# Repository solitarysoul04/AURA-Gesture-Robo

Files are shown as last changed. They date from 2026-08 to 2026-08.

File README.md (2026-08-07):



# AURA (Autonomous & Unmanned Reconnaissance Agent) Rover🚙

AURA Rover is a visionary project which I brainstormed during building for Macondo by HackClub. It is an autonomous project that will use a computer vision interface which will incorporate MediaPipe and OpenCV which will detect and read the hand gestures on-board for hopefully successful movement of the rover. This idea was brainstormed to replace the use of joystick and sit back lazy controlling the rover with just your physical hands assisted by ESP32-CAM feed on your system.

## 🌟 Key Features
- Dual-Hand Control: Pinching fingers of left hand will trigger the throttle and right hand gestures will act as an steering using OpenCV and MediaPipe.
- Dual-Band Architecture: Video will be transmitted via ESP32-CAM high-bandwidth FPV Wi-Fi and for Zero-Latency Motor Controls, 2.4GHz RF on nRF24L01 will be used.
- Two HC-SR04 ultrasonic sensors: Since the rover will be autonomous, for safety and instant braking of the rover, two ultrasonic sensors (one at front and another at back) will keep a watch on obstacles and will avoid any crash by stopping rover if something is detected within 15cm and will not accept the wireless commands.

## 🛒 BoM 
| Category | Product Name | SKU | Qty | Price/Unit (INR) | Link |
| :--- | :--- | :--- | :--- | :--- | :--- |
| Electronics | RF Nano Integrated NRF24L01 Wireless Module | 1121399 | 2 | 1159 | [Buy](https://robu.in/?s=1121399&post_type=product) |
| Electronics | Nano CH340 Chip Board Without USB Cable | 16906 | 2 | 195 | [Buy](https://robu.in/?s=16906&post_type=product) |
| Electronics | ESP32-CAM WiFi + Bluetooth Module | R262524 | 1 | 709 | [Buy](https://robu.in/?s=R262524&post_type=product) |
| Electronics | L298N Dual H Bridge Motor Driver | 51971 | 1 | 176 | [Buy](https://robu.in/?s=51971&post_type=product) |
| Electronics | HC-SR04 Ultrasonic Range Finder Sensor | 2444 | 1 | 65 | [Buy](https://robu.in/?s=2444&post_type=product) |
| Power | Pro-Range INR 18650 11.1V 2000mAh 3S1P Li-Ion Battery | 1237659 | 1 | 899 | [Buy](https://robu.in/?s=1237659&post_type=product) |
| Power | LM2596S DC-DC Buck Converter Power Supply | 11548 | 1 | 42 | [Buy](https://robu.in/?s=11548&post_type=product) |
| Power | Battery Charger 3S Li-ion 12.6V 5A | 1158326 | 1 | 1773 | [Buy](https://robu.in/?s=1158326&post_type=product) |
| Hardware | EasyMech Warrior Chassis for Robotics | 43327 | 1 | 1386 | [Buy](https://robu.in/?s=43327&post_type=product) |
| Hardware | Pro-Range 12V 300 RPM Johnson Geared DC Motor | 5728 | 4 | 540 | [Buy](https://robu.in/?s=5728&post_type=product) |
| Hardware | 85mm Large Robot Smart Car Wheel 38mm Wide | 31509 | 4 | 209 | [Buy](https://robu.in/?s=31509&post_type=product) |
| Hardware | 6mm Hex Motor Coupling 30mm Length | 42874 | 4 | 81 | [Buy](https://robu.in/?s=42874&post_type=product) |
| Cabling | Male to Male Jumper Wires 40Pcs 20cm | 7447 | 1 | 46 | [Buy](https://robu.in/?s=7447&post_type=product) |
| Cabling | 10 Wire Male to Female Jumper Wires 20cm | R160077 | 4 | 14 | [Buy](https://robu.in/?s=R160077&post_type=product) |
| Cabling | 22AWG High Quality Ultra Flexible Silicone Wire - Black | 1824995 | 1 | 18 | [Buy](https://robu.in/?s=1824995&post_type=product) |
| Cabling | 22AWG Single Core Teflon Wire - Red | R257340 | 1 | 24 | [Buy](https://robu.in/?s=R257340&post_type=product) |
| Cabling | Female to Female DuPont Line 40 Pin 30cm | 31321 | 1 | 61 | [Buy](https://robu.in/?s=31321&post_type=product) |
| Cabling | Arduino Nano USB A-Mini B 1.2m Cable | 17844 | 1 | 44 | [Buy](https://robu.in/?s=17844&post_type=product) |
| Cabling | USB TO UART TTL 5V 3.3V FT232RL Adapter | 9707 | 1 | 89 | [Buy](https://robu.in/?s=9707&post_type=product) |
| Consumables | Nylon Cable Zip Ties 150mm White (Pack of 100) | 18279 | 1 | 78 | [Buy](https://robu.in/?s=18279&post_type=product) |
| Consumables | Nylon Cable Zip Ties 300mm White (Pack of 100) | 18280 | 1 | 109 | [Buy](https://robu.in/?s=18280&post_type=product) |
| Consumables | Heat Shrink sleeve 20mm Black | R150615 | 1 | 74 | [Buy](https://robu.in/?s=R150615&post_type=product) |
| Consumables | All Purpose Hot Melt Glue Sticks - 5pcs | 6005 | 1 | 79 | [Buy](https://robu.in/?s=6005&post_type=product) |
| Consumables | Noel Solder Wire 60/40 1.00mm 50gm | 720480 | 1 | 299 | [Buy](https://robu.in/?s=720480&post_type=product) |
| Consumables | Noel FLUX soldering paste-10g | 762465 | 1 | 25 | [Buy](https://robu.in/?s=762465&post_type=product) |
| Prototyping | GL-12 840 Points Solderless Breadboard | 24441 | 1 | 59 | [Buy](https://robu.in/?s=24441&post_type=product) |
| Tools | Screwdriver Set 52 in 1 | 972456 | 1 | 800 | [Buy](https://robu.in/?s=972456&post_type=product) |
| Tools | Soldron 50W 230V Soldering Iron | 143296 | 1 | 699 | [Buy](https://robu.in/?s=143296&post_type=product) |
| Tools | TE-801 LED Magnifier PCB Soldering Stand | 17940 | 1 | 441 | [Buy](https://robu.in/?s=17940&post_type=product) |
| Tools | Multitec 02DX Self Adjusting Wire Cutter - Stripper | 617869 | 1 | 256 | [Buy](https://robu.in/?s=617869&post_type=product) |
| Tools | HTC DM-830L Digital Pocket Multimeter | 775689 | 1 | 649 | [Buy](https://robu.in/?s=775689&post_type=product) |
| Tools | Standard Temp 60Watt Hot Melt Glue Gun | 5998 | 1 | 251 | [Buy](https://robu.in/?s=5998&post_type=product) |
| Tools | Stanley Black+DECKER KR5010V Hammer Drill | R111278 | 1 | 2369 | [Buy](https://robu.in/?s=R111278&post_type=product) |

## 📐 3D CAD Model
This build was done natively in Onshape, with the structural layout and stacking of components. 
**[Link to Onshape Public 3D Model](https://cad.onshape.com/documents/1ed37dd0b596b430698f5eb2/w/aa1a3a995dd5a0a3a9e055b1/e/f5aa9d2bf4de66af82fadf2e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)**

## 🛠️ Assembly Instructions

Once I have the required hardware parts I will put the parts together and wire the hardware/electronics as follows:

**1. Mechanical**
* First step will be to assemble the EasyMech Warrior aluminium chassis using the screws and resources included within the kit.
* Further, I will attach the 6mm Motor Couplings to each of four Johnson Geared Motors and tighten them up.
* Fit the wheels on motors, and install them on chassis along with motors. 

**2. Electronics**
* The L298N Motor Driver, LM2596 Buck Converter and Arduino Nanos will be glued to the base using either double sided foam tape or hot glue as seem necessary.
* ESP32-CAM, HC-SR04 and other necessary components will be glued accordingly to the CAD Model submitted.
* 11.1V Li-ion battery will be tied up with nylon zip to fix it.

**3. Wiring**
* 11.1V battery will be connected to main power connectors on L298N motor driver.
* Battery wires will be stripped off and will be connected to LM2596 Buck Converter.
* All other necessary connections of ESP32-CAM, Arduino, 5V, etc. will be done with reference to below Mermaid wiring diagram.

**4. Firmware**
* For logic processing, we will first install Arduino IDE to program the microcontroller and "RF24" library too for the radios.
* Base station Arduino Nano will be connected to laptop using the USB Cable to upload the `Base_Station.ino` file.
* For rover movement, another Arduino Nano will be updated with the code file `Rover_Brain.ino`.
* For successful working of the scripts, firmwares and GUI, corresponding dependencies need to be installed... This must be done via the terminal by entering command: `pip install opencv-python mediapipe pyserial numpy requests`.
* Finally, COM port need to be changed into the PORT of our base station Arduino Nano and run the script `Mission_Control.py` to open the hand tracking GUI.

## 🔌 Hardware Wiring Diagram

```mermaid
graph TD
    %% Power Distribution
    BAT([11.1V Li-Ion Battery]) ==>|11.1V Power| L298N[L298N Motor Driver]
    BAT ==>|11.1V Power| BUCK[LM2596 Buck Converter]
    BUCK ==>|Steps down to 5V| 5V_RAIL((5V Logic Rail))

    %% 5V Connections
    5V_RAIL -->|VIN| NANO[RF Nano Integrated]
    5V_RAIL -->|5V Pin| ESP[ESP32-CAM]
    5V_RAIL -->|VCC| HC1[Front HC-SR04]
    
    %% Common Ground
    GND_RAIL((Common GND)) --- BAT
    GND_RAIL --- BUCK
    GND_RAIL --- L298N
    GND_RAIL --- NANO
    GND_RAIL --- ESP
    GND_RAIL --- HC1

    %% Data Connections
    NANO -.->|D5, D10| L298N_PWM(L298N ENA/ENB)
    NANO -.->|D2, D3, D4, D6| L298N_DIR(L298N IN1-IN4)
    NANO -.->|A0, A1| HC1_DATA(HC-SR04 Trig/Echo)

    %% Motor Outputs
    L298N ===>|OUT1, OUT2| ML((Left Gear Motors))
    L298N ===>|OUT3, OUT4| MR((Right Gear Motors))

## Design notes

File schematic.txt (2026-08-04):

=====================================================================
                          WIRING SCHEMATIC
=====================================================================

[11.1V Li-Ion Battery]
    |           |
    |           +-------------------------------+
   (+)                                         (+)
[LM2596 Buck Converter]                 [L298N Motor Driver]
(Tuned to exactly 5V)                   (11.1V Motor Power)
   (-)                                         (-)
    |                                           |
    +-------------------------------------------+---> [Common GND]

=====================================================================
                      LOGIC POWER (5V)
=====================================================================

         [5V Power]                     [Common GND]
             |                                |
             +--> VIN [RF Nano] GND <---------+
             |                                |
             +--> 5V  [ESP32-CAM] GND <-------+
             |                                |
             +--> VCC [HC-SR04] GND <---------+

=====================================================================
                      DATA & SIGNAL ROUTING
=====================================================================

[RF Nano Integrated]                      [L298N Motor Driver]
     D5  (PWM)---------------------------> ENA (Left Speed)
     D2  --------------------------------> IN1 (Left FWD)
     D3  --------------------------------> IN2 (Left REV)
     
     D10 (PWM)---------------------------> ENB (Right Speed)
     D4  --------------------------------> IN3 (Right FWD)
     D6  --------------------------------> IN4 (Right REV)

[RF Nano Integrated]                      [HC-SR04 Ultrasonic]
     A0  --------------------------------> TRIG
     A1  --------------------------------> ECHO

=====================================================================
                         MOTOR OUTPUTS
=====================================================================

[L298N Motor Driver]                      [DC Gear Motors]
     OUT1 & OUT2 ------------------------> Left Side Motors
     OUT3 & OUT4 ------------------------> Right Side Motors

=====================================================================

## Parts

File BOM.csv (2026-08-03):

Category | Product Name | SKU | Quantity | Price/unit (INR) | Purchase Link
Electronics | RF Nano Integrated NRF24L01 Wireless Module | 1121399 | 2 | 1159 | https://robu.in/?s=1121399&post_type=product
Electronics | Nano CH340 Chip Board Without USB Cable | 16906 | 2 | 195 | https://robu.in/?s=16906&post_type=product
Electronics | ESP32-CAM WiFi + Bluetooth Module | R262524 | 1 | 709 | https://robu.in/?s=R262524&post_type=product
Electronics | L298N Dual H Bridge Motor Driver | 51971 | 1 | 176 | https://robu.in/?s=51971&post_type=product
Electronics | HC-SR04 Ultrasonic Range Finder Sensor | 2444 | 1 | 65 | https://robu.in/?s=2444&post_type=product
Power | Pro-Range INR 18650 11.1V 2000mAh 3S1P Li-Ion Battery | 1237659 | 1 | 899 | https://robu.in/?s=1237659&post_type=product
Power | LM2596S DC-DC Buck Converter Power Supply | 11548 | 1 | 42 | https://robu.in/?s=11548&post_type=product
Power | Battery Charger 3S Li-ion 12.6V 5A | 1158326 | 1 | 1773 | https://robu.in/?s=1158326&post_type=product
Hardware | EasyMech Warrior Chassis for Robotics | 43327 | 1 | 1386 | https://robu.in/?s=43327&post_type=product
Hardware | Pro-Range 12V 300 RPM Johnson Geared DC Motor | 5728 | 4 | 540 | https://robu.in/?s=5728&post_type=product
Hardware | 85mm Large Robot Smart Car Wheel 38mm Wide | 31509 | 4 | 209 | https://robu.in/?s=31509&post_type=product
Hardware | 6mm Hex Motor Coupling 30mm Length | 42874 | 4 | 81 | https://robu.in/?s=42874&post_type=product
Cabling | Male to Male Jumper Wires 40Pcs 20cm | 7447 | 1 | 46 | https://robu.in/?s=7447&post_type=product
Cabling | 10 Wire Male to Female Jumper Wires 20cm | R160077 | 4 | 14 | https://robu.in/?s=R160077&post_type=product
Cabling | 22AWG High Quality Ultra Flexible Silicone Wire - Black | 1824995 | 1 | 18 | https://robu.in/?s=1824995&post_type=product
Cabling | 22AWG Single Core Teflon Wire - Red | R257340 | 1 | 24 | https://robu.in/?s=R257340&post_type=product
Cabling | Female to Female DuPont Line 40 Pin 30cm | 31321 | 1 | 61 | https://robu.in/?s=31321&post_type=product
Cabling | Arduino Nano USB A-Mini B 1.2m Cable | 17844 | 1 | 44 | https://robu.in/?s=17844&post_type=product
Cabling | USB TO UART TTL 5V 3.3V FT232RL Adapter | 9707 | 1 | 89 | https://robu.in/?s=9707&post_type=product
Consumables | Nylon Cable Zip Ties 150mm White (Pack of 100) | 18279 | 1 | 78 | https://robu.in/?s=18279&post_type=product
Consumables | Nylon Cable Zip Ties 300mm White (Pack of 100) | 18280 | 1 | 109 | https://robu.in/?s=18280&post_type=product
Consumables | Heat Shrink sleeve 20mm Black | R150615 | 1 | 74 | https://robu.in/?s=R150615&post_type=product
Consumables | All Purpose Hot Melt Glue Sticks - 5pcs | 6005 | 1 | 79 | https://robu.in/?s=6005&post_type=product
Consumables | Noel Solder Wire 60/40 1.00mm 50gm | 720480 | 1 | 299 | https://robu.in/?s=720480&post_type=product
Consumables | Noel FLUX soldering paste-10g | 762465 | 1 | 25 | https://robu.in/?s=762465&post_type=product
Prototyping | GL-12 840 Points Solderless Breadboard | 24441 | 1 | 59 | https://robu.in/?s=24441&post_type=product
Tools | Screwdriver Set 52 in 1 | 972456 | 1 | 800 | https://robu.in/?s=972456&post_type=product
Tools | Soldron 50W 230V Soldering Iron | 143296 | 1 | 699 | https://robu.in/?s=143296&post_type=product
Tools | TE-801 LED Magnifier PCB Soldering Stand | 17940 | 1 | 441 | https://robu.in/?s=17940&post_type=product
Tools | Multitec 02DX Self Adjusting Wire Cutter - Stripper | 617869 | 1 | 256 | https://robu.in/?s=617869&post_type=product
Tools | HTC DM-830L Digital Pocket Multimeter | 775689 | 1 | 649 | https://robu.in/?s=775689&post_type=product
Tools | Standard Temp 60Watt Hot Melt Glue Gun | 5998 | 1 | 251 | https://robu.in/?s=5998&post_type=product
Tools | Stanley Black+DECKER KR5010V Hammer Drill | R111278 | 1 | 2369 | https://robu.in/?s=R111278&post_type=product

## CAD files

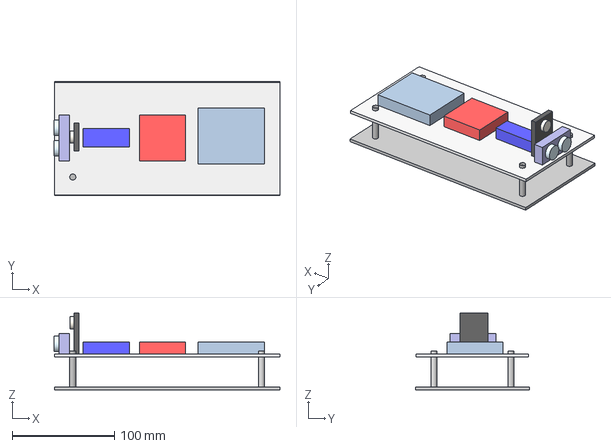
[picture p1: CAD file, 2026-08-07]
CAD File/Main body.step
220.5 x 111.2 x 75.0 mm

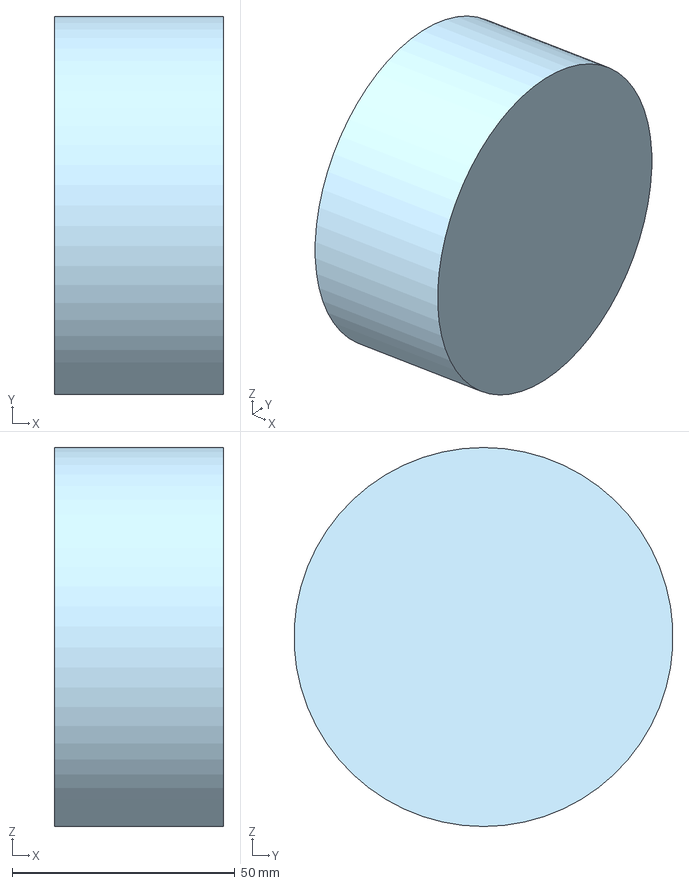
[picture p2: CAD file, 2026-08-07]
CAD File/wheels.step
38.0 x 84.9 x 85.0 mm

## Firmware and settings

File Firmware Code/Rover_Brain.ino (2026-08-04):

#include <SPI.h>
#include <nRF24L01.h>
#include <RF24.h>

// Hardware Pins
#define CE_PIN 9
#define CSN_PIN 8

// L298N Motor Driver Pins
#define IN1 2
#define IN2 3
#define IN3 4
#define IN4 6
#define ENA 5 
#define ENB 10

// Front HC-SR04 Pins
#define TRIG_FRONT A0
#define ECHO_FRONT A1

RF24 radio(CE_PIN, CSN_PIN);
const byte address[6] = "00001"; 
const int SAFE_DISTANCE_CM = 15; 

struct Data_Package {
  char direction;
  byte speed;
};
Data_Package data = {'S', 0}; // safe STOP state

void setup() {
  pinMode(IN1, OUTPUT); pinMode(IN2, OUTPUT);
  pinMode(IN3, OUTPUT); pinMode(IN4, OUTPUT);
  pinMode(ENA, OUTPUT); pinMode(ENB, OUTPUT);

  pinMode(TRIG_FRONT, OUTPUT); 
  pinMode(ECHO_FRONT, INPUT);

  radio.begin();
  radio.openReadingPipe(0, address);
  radio.setPALevel(RF24_PA_LOW);
  radio.startListening();
}

void loop() {
  // Front Sensor
  int frontDist = getDistance(TRIG_FRONT, ECHO_FRONT);

  if (radio.available()) {
    radio.read(&data, sizeof(Data_Package));
  }

  if (data.direction == 'F' && frontDist > 0 && frontDist < SAFE_DISTANCE_CM) {
    data.direction = 'S'; 
    data.speed = 0;
  }

  executeMotorCommand(data.direction, data.speed);
}

int getDistance(int trigPin, int echoPin) {
  digitalWrite(trigPin, LOW); delayMicroseconds(2);
  digitalWrite(trigPin, HIGH); delayMicroseconds(10);
  digitalWrite(trigPin, LOW);
  
  long duration = pulseIn(echoPin, HIGH, 15000); 
  if (duration == 0) return 999; 
  return duration * 0.034 / 2;
}

void executeMotorCommand(char dir, byte spd) {
  analogWrite(ENA, spd);
  analogWrite(ENB, spd);

  switch (dir) {
    case 'F': digitalWrite(IN1, HIGH); digitalWrite(IN2, LOW); digitalWrite(IN3, HIGH); digitalWrite(IN4, LOW); break;
    case 'B': digitalWrite(IN1, LOW); digitalWrite(IN2, HIGH); digitalWrite(IN3, LOW); digitalWrite(IN4, HIGH); break;
    case 'L': digitalWrite(IN1, LOW); digitalWrite(IN2, HIGH); digitalWrite(IN3, HIGH); digitalWrite(IN4, LOW); break;
    case 'R': digitalWrite(IN1, HIGH); digitalWrite(IN2, LOW); digitalWrite(IN3, LOW); digitalWrite(IN4, HIGH); break;
    case 'S': default: digitalWrite(IN1, LOW); digitalWrite(IN2, LOW); digitalWrite(IN3, LOW); digitalWrite(IN4, LOW); break;
  }
}

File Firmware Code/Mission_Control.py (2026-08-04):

import cv2
import mediapipe as mp
import serial
import time
import numpy as np
import math

# Configuration
COM_PORT = 'COM3'         # Base Station Nano port
ESP32_IP = '192.168.1.50' # ESP32-CAM IP Address
URL = f"http://{ESP32_IP}:81/stream"

# Arduino Connection
try:
    arduino = serial.Serial(COM_PORT, 115200, timeout=1)
    time.sleep(2)
except Exception as e:
    print(f"Serial Error: {e}")
    arduino = None

cap_webcam = cv2.VideoCapture(0)
cap_rover = cv2.VideoCapture(URL)

mp_hands = mp.solutions.hands
hands = mp_hands.Hands(max_num_hands=2, min_detection_confidence=0.7)
mp_draw = mp.solutions.drawing_utils

last_cmd_time = 0

def get_direction(hand_landmarks):
    tips = [8, 12, 16, 20]
    pips = [6, 10, 14, 18]
    fingers_up = []
    
    fingers_up.append(1 if hand_landmarks.landmark[4].x < hand_landmarks.landmark[3].x else 0)

    for i in range(4):
        fingers_up.append(1 if hand_landmarks.landmark[tips[i]].y < hand_landmarks.landmark[pips[i]].y else 0)
            
    if fingers_up == [0, 1, 0, 0, 0]: return 'F'  # Index up -> Forward
    if fingers_up == [0, 1, 1, 0, 0]: return 'B'  # Index + Middle up -> Backward
    if fingers_up == [1, 1, 0, 0, 0]: return 'L'  # Thumb + Index up -> Left
    if fingers_up == [1, 1, 1, 0, 0]: return 'R'  # Thumb + Index + Middle up -> Right
    return 'S' # Default -> Stop

def get_throttle(hand_landmarks):
    x1, y1 = hand_landmarks.landmark[4].x, hand_landmarks.landmark[4].y
    x2, y2 = hand_landmarks.landmark[8].x, hand_landmarks.landmark[8].y
    
    dist = math.hypot(x2 - x1, y2 - y1)
    speed = np.interp(dist, [0.05, 0.25], [0, 255])
    return int(np.clip(speed, 0, 255))

while True:
    ret1, frame_webcam = cap_webcam.read()
    ret2, frame_rover = cap_rover.read()
    if not ret1: break

    frame_webcam = cv2.flip(frame_webcam, 1) 
    rgb_frame = cv2.cvtColor(frame_webcam, cv2.COLOR_BGR2RGB)
    result = hands.process(rgb_frame)
    
    cmd_char = 'S'
    speed_val = 0

    if result.multi_hand_landmarks and result.multi_handedness:
        for idx, hand_handedness in enumerate(result.multi_handedness):
            label = hand_handedness.classification[0].label 
            hand_landmarks = result.multi_hand_landmarks[idx]
            mp_draw.draw_landmarks(frame_webcam, hand_landmarks, mp_hands.HAND_CONNECTIONS)
            
            if label == "Right": speed_val = get_throttle(hand_landmarks)
            elif label == "Left": cmd_char = get_direction(hand_landmarks)

    if time.time() - last_cmd_time > 0.1: 
        if arduino:
            payload = f"{cmd_char},{speed_val}\n"
            arduino.write(payload.encode())
        last_cmd_time = time.time()

    # Dashboard
    h, w = 480, 640
    frame_webcam = cv2.resize(frame_webcam, (w, h))
    
    if ret2:
        frame_rover = cv2.resize(frame_rover, (w, h))
    else:
        frame_rover = np.zeros((h, w, 3), dtype=np.uint8)
        cv2.putText(frame_rover, "Wi-Fi FPV LOST", (180, 240), cv2.FONT_HERSHEY_SIMPLEX, 1, (0,0,255), 2)

    stats_panel = np.zeros((h, 300, 3), dtype=np.uint8)
    cv2.putText(stats_panel, "AURA CMD CENTER", (20, 40), cv2.FONT_HERSHEY_SIMPLEX, 0.8, (255,255,255), 2)
    cv2.putText(stats_panel, f"DIR: {cmd_char}", (20, 100), cv2.FONT_HERSHEY_SIMPLEX, 0.8, (0,255,0), 2)
    cv2.putText(stats_panel, f"PWR: {speed_val}", (20, 160), cv2.FONT_HERSHEY_SIMPLEX, 0.8, (0,255,255), 2)
    
    # Throttle Bar
    bar_height = int(np.interp(speed_val, [0, 255], [0, 200]))
    cv2.rectangle(stats_panel, (50, 400), (100, 400 - bar_height), (0, 255, 255), cv2.FILLED)
    cv2.rectangle(stats_panel, (50, 400), (100, 200), (255, 255, 255), 2)
    
    # Final Dashboard
    dashboard = cv2.hconcat([frame_webcam, frame_rover, stats_panel])
    cv2.imshow("AURA Telemetry Interface", dashboard)
    
    # Press 'q' to safely exit
    if cv2.waitKey(1) & 0xFF == ord('q'): break

cap_webcam.release()
cap_rover.release()
cv2.destroyAllWindows()
if arduino: arduino.close()

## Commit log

2026-08-03 Add files via upload
    3D Model STEP file
    [AURA.step]
2026-08-03 Add BOM.csv with electronic components details
    Added a Bill of Materials (BOM) CSV file containing various electronic components, their categories, SKUs, quantities, prices, and purchase links.
    [BOM.csv]
2026-08-03 Update README with hardware wiring diagram
    Added a hardware wiring diagram using Mermaid syntax.
2026-08-03 Update price column header in BOM.csv
    [BOM.csv]
2026-08-04 Add assembly instructions to README
    Added assembly instructions for the AURA Rover project, detailing mechanical assembly, electronics setup, wiring, and firmware installation.
2026-08-07 Revise README for AURA Rover project details
    Updated project description and key features for clarity. Revised assembly instructions for mechanical, electronics, wiring, and firmware sections.
